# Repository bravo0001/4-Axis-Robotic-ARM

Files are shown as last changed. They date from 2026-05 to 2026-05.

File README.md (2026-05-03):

# 🦾 Wireless 4-DOF Robotic Arm




A wireless 4-Degrees-of-Freedom (4-DOF) robotic arm featuring a custom ESP32-based motherboard, **ESP-NOW peer-to-peer communication** for ultra-low-latency control, **12V DC motors** driven by relay H-Bridges, and **potentiometer-based absolute closed-loop feedback** processed through a **Kalman Filter** for smooth, noise-free motion. The system is controlled by a natural interface (wearable glove + IMUs + fingertip buttons). This project demonstrates advanced PCB design, digital signal processing, and industrial-grade mechatronics.

---

## 📐 System Architecture

```
┌─────────────────────────────────┐        ESP-NOW (P2P)        ┌─────────────────────────────────┐
│         TRANSMITTER             │ ──────────────────────────► │         RECEIVER / MOTHERBOARD  │
│                                 │       ~1ms latency          │                                 │
│  ESP32 DevKit                   │                             │  ESP32 Custom PCB               │
│  2x MPU-6050(IMU Sensor)        │                             │  4× 12V DC Motors               │
│  Kalman Filter (on-board)       │                             │  8× SPDT Relay H-Bridge         │
│  Reads 4-axis orientation       │                             │  4× 10kΩ Potentiometers (ADC1)  |
│                                 |                             |  12v Booster module             |
│                                 │                             │  Closed-Loop State Machine      │
└─────────────────────────────────┘                             └─────────────────────────────────┘
```

---

## ✨ Key Features

| Feature | Detail |
|---|---|
| **Communication** | ESP-NOW (Peer-to-Peer, no router required) |
| **Latency** | ~1 ms wireless transmission |
| **Degrees of Freedom** | 4-DOF (Base, Shoulder, Elbow, Wrist) |
| **Feedback** | Closed-loop absolute encoding via 10kΩ potentiometers |
| **ADC Pins (Feedback)** | GPIO 34, 35, 36, 39 (ADC1 — safe with Wi-Fi/ESP-NOW) |
| **Signal Processing** | Kalman Filter for IMU noise reduction |
| **Control Interface** | Natural wearable glove (IMUs + fingertip buttons) |
| **Motor Drive** | 12V DC motors via Relay H-Bridge circuits |
| **Firmware Architecture** | Non-blocking state machine on Receiver |

---

## 📁 Repository Structure

```
4-Axis-Robotic-ARM/
├── Firmware/
│   ├── Transmitter/
│   │   └── Transmitter.ino        # ESP32 transmitter: IMU read + Kalman + ESP-NOW send
│   └── Receiver/
│       └── Receiver.ino           # ESP32 receiver: ESP-NOW recv + state machine + motor control
├── Calibration/
│   ├── All_Axis_Calibration.ino   # Multi-axis potentiometer calibration (all 4 axes simultaneously)
│   ├── Axis_degree_calibration.ino # Single-axis calibration for debugging individual axes
│   └── README.md                  # Calibration documentation
├── Hardware/
│   ├── Schematics/
│   │   └── PLACEHOLDER.md         # Add KiCad / Eagle schematic files here
│   ├── Transmitter_glove-Natural_interface/
│   │   ├── Glove.jpeg             # Wearable transmitter glove overview (palm ESP32 + forearm band)
│   │   ├── Buttons.jpg            # Fingertip push-buttons for gripper control (open/close)
│   │   └── MPUS.jpg               # MPU-6050 sensor placement (forearm + palm)
│   └── PCB_Gerbers/
│       └── PLACEHOLDER.md         # Add Gerber files for PCB fabrication here
├── .gitignore                     # Arduino / PlatformIO ignores
├── LICENSE                        # MIT License
└── README.md
```

---

## ⚙️ Technical Specifications

### Communication
- **Protocol:** ESP-NOW (IEEE 802.11 based, Layer 2)
- **Topology:** Point-to-Point (Transmitter → Receiver)
- **Payload:** Custom `struct` carrying 4-axis angle data (floats)
- **Range:** Up to ~200 m line-of-sight
- **Latency:** ~1 ms

### Transmitter (ESP32 + IMU)
- Reads raw accelerometer & gyroscope data from IMU ( MPU-6050 via I²C)
- Applies **Kalman Filter** to fuse accel + gyro and eliminate sensor drift/noise
- Packs filtered 4-axis angles into a data packet and transmits via ESP-NOW

### Transmitter (Wearable Glove Interface)
The transmitter is implemented as a wearable, natural interface: a glove with an ESP32 mounted on the palm and a small forearm band. The wearable contains two MPU-6050 IMUs and two fingertip push-buttons used to control the gripper. This setup maps natural arm and hand motions into robot joint commands for intuitive control.

- **Forearm band MPU-6050**: mounted on the arm band to capture arm orientation (used for arm/base/shoulder control — X and Z axes).
- **Palm MPU-6050**: mounted on the palm to capture hand/wrist orientation (X axis).
- **ESP32 (palm-mounted)**: reads both IMUs over I²C and the fingertip push-buttons, packs orientation and button states into the ESP-NOW payload, and transmits to the Receiver.
- **Fingertip buttons**: two discrete push-buttons embedded at the fingertips — mapped to gripper actions (open / close).

Usage and mapping notes:
- Forearm MPU → arm orientation (map to base/shoulder as configured in `Transmitter.ino`).
- Palm MPU → wrist/hand orientation (map to wrist joint in the receiver state machine).
- Buttons → gripper open/close flags included in the ESP-NOW packet (sent as `uint8_t` or `bool` fields).
- This wearable arrangement is intended as a natural interface: the user performs normal arm/hand motions and fingertip presses to control the robotic arm and gripper.

Practical tips:
- Use I2C for both IMUs; if both sensors share the same address use a small I2C multiplexer or reconfigure addresses where supported.
- Debounce button inputs in firmware (software debounce or simple RC hardware) to avoid spurious commands.
- Calibrate each IMU and verify axis alignment between sensor frames and the robot joint frames before relying on production mappings.
- Keep the ESP32's ground common with the sensor grounds; use short wiring for the palm MPU for best results.

Suggested addition to the ESP-NOW payload (example):
```cpp
typedef struct {
  float axis1_angle;
  float axis2_angle;
  float axis3_angle;
  float axis4_angle;
  uint8_t gripper_open;   // 0/1
  uint8_t gripper_close;  // 0/1
} RoboArmPacket;
```

These fields allow the receiver to process continuous orientation values and discrete gripper commands together.

**Wearable photos**

Below are photos of the actual wearable transmitter (glove + forearm band) used as the natural interface. The palm-mounted ESP32, the two MPU-6050 modules (palm + forearm), and the fingertip push-buttons are shown.

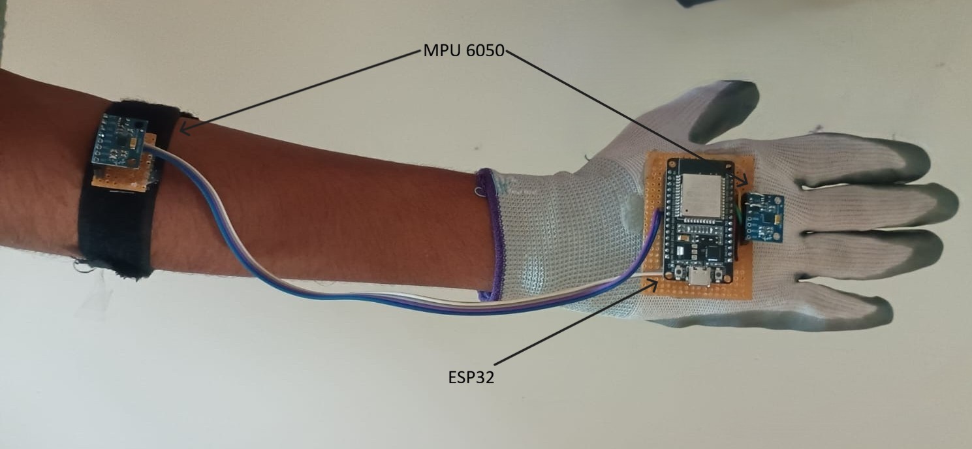
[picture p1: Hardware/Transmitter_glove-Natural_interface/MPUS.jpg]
Palm view — ESP32 and palm MPU mounted on glove


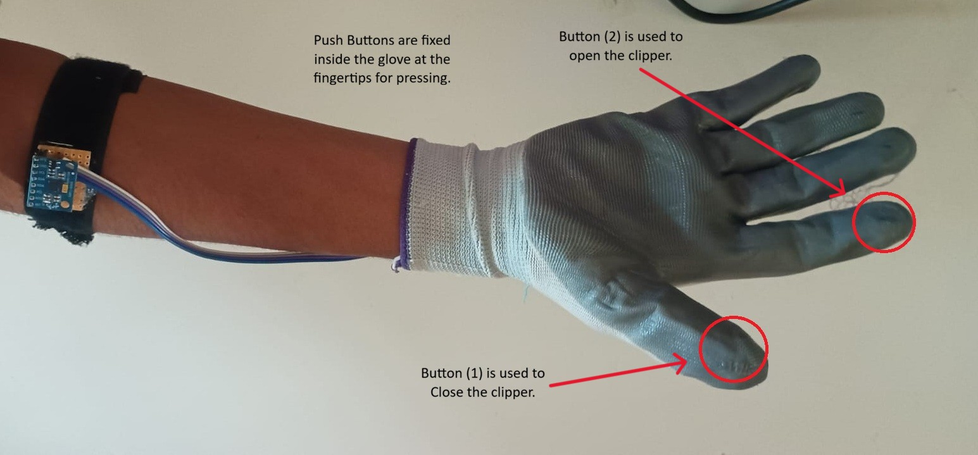
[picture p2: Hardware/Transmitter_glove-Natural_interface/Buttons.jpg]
Fingertip buttons — two push-buttons embedded at fingertips (open/close gripper)


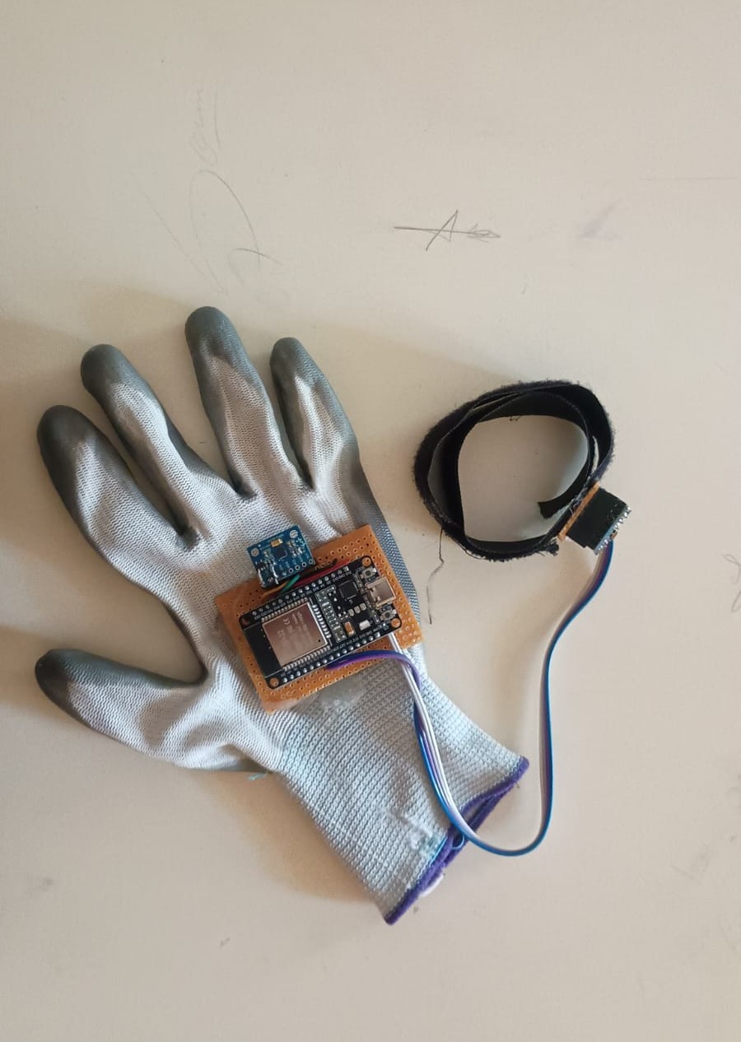
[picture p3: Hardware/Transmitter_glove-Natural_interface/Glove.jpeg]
Overview — forearm band MPU, wiring to palm MPU and ESP32


Firmware/VID_20260423_234357317.mp4~2.mp4
### Receiver / Motherboard (Custom ESP32 PCB)
- Receives angle packets via `OnDataRecv` ESP-NOW callback (interrupt-driven)
- Runs a **non-blocking state machine** for each axis to drive motors to target positions
- Reads current joint positions from 10kΩ potentiometers on **ADC1 pins** (GPIO 34, 35, 36, 39)
  - ADC1 is used because ADC2 is unavailable when Wi-Fi / ESP-NOW is active
- Drives **12V DC motors** via Relay H-Bridge circuits (direction + enable control)

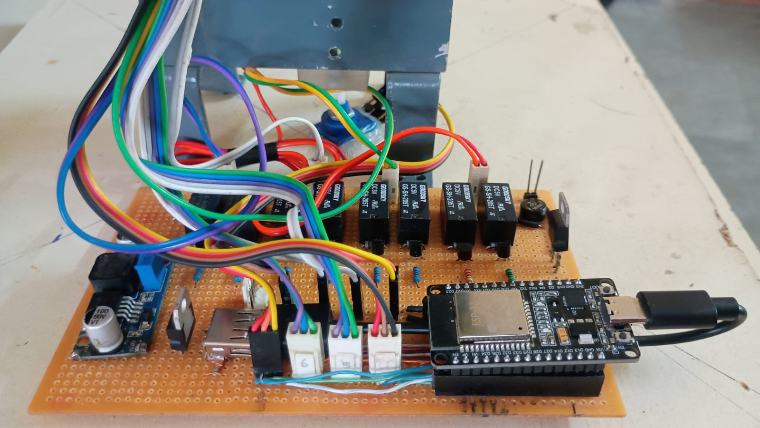
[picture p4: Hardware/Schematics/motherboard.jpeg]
Receiver / Motherboard — assembled ESP32 motherboard and relay board


**Demonstration video**

See the demo to understand the system in action. Add a `demo.mp4` file to `Firmware/Demo/` or provide a YouTube link and paste it below. Example embed (YouTube):

<table>
  <tr>
    <td width="400">
      <video src="https://github.com/user-attachments/assets/9cfaaa7f-c85e-4afe-878e-ee82e51a2cbb" controls>
      </video>
    </td>
  </tr>
</table>

If you have a local mp4 file named `demo.mp4`, place it in `Hardware/Demo/` and GitHub will render a downloadable file; to stream in README, upload the video to YouTube and embed as above for best compatibility.

### Feedback / Encoding
- **Type:** Absolute analog encoding (no homing required on power-up)
- **Sensor:** 10kΩ potentiometer per axis
- **ADC Resolution:** 12-bit (0–4095 mapped to 0°–270°)
- **Pins:** GPIO 34 (Axis 1), GPIO 35 (Axis 2), GPIO 36 (Axis 3), GPIO 39 (Axis 4)

### Kalman Filter (Digital Signal Processing)
- Single-variable discrete Kalman Filter implemented in C++
- **State:** Joint angle (degrees)
- **Process noise (Q):** Tunable — accounts for motor vibration & mechanical play
- **Measurement noise (R):** Tunable — accounts for ADC quantisation & potentiometer noise
- Runs on both Transmitter (IMU fusion) and Receiver (feedback smoothing)

---

## � Calibration

The `/Calibration/` folder contains two Arduino sketches for calibrating and testing the potentiometer feedback system:

### `All_Axis_Calibration.ino`
- Reads all four potentiometer axes simultaneously (GPIO 34, 35, 36, 39)
- Displays raw ADC values, voltage readings, and calculated angles in real-time
- Useful for verifying all axes are functioning correctly
- **Update interval:** 250 ms

### `Axis_degree_calibration.ino`
- Single-axis debugging sketch targeting GPIO 34
- Ideal for troubleshooting individual potentiometer connections
- Displays detailed readings: raw value, voltage, and angle
- **Update interval:** 100 ms

**Usage:**
1. Upload the desired calibration sketch to the Receiver ESP32
2. Open Serial Monitor at **115200 baud**
3. Rotate each potentiometer and verify the readings are linear and within expected ranges (0°–270°)
4. Adjust potentiometer range constants (270.0) in the code if your sensors have different specifications

### Running All_Axis_Calibration.ino
Upload and run this sketch on the Receiver ESP32 to simultaneously test all four potentiometers:
```cpp
// Array of pins you want to read
const int potPins[] = {34, 35, 36, 39};
const int numPins = 4;

void setup() {
  Serial.begin(115200);
  
  // ESP32 ADC setup
  analogReadResolution(12); // 0-4095 range
  analogSetAttenuation(ADC_11db); // Standard for 0-3.3V range

  Serial.println("Multi-Pin Potentiometer Initialization...");
}

void loop() {
  for (int i = 0; i < numPins; i++) {
    int rawValue = analogRead(potPins[i]);
    
    // Calculate voltage and degrees
    float voltage = rawValue * (3.3 / 4095.0);
    float degrees = (rawValue / 4095.0) * 270.0;

    // Print label for each pin
    Serial.print("PIN "); 
    Serial.print(potPins[i]);
    Serial.print(": [Raw: ");
    Serial.print(rawValue);
    Serial.print(" | Volts: ");
    Serial.print(voltage, 2);
    Serial.print("V | Ang: ");
    Serial.print(degrees, 1);
    Serial.print("°]   ");
  }
  
  Serial.println();
  delay(250); // Delay for readability
}
```

**Expected Serial Output:**
```
Multi-Pin Potentiometer Initialization...
PIN 34: [Raw: 2048 | Volts: 1.65V | Ang: 135.0°]   PIN 35: [Raw: 1024 | Volts: 0.83V | Ang: 67.5°]   PIN 36: [Raw: 3072 | Volts: 2.48V | Ang: 202.5°]   PIN 39: [Raw: 512 | Volts: 0.41V | Ang: 33.8°]
```

### Running Axis_degree_calibration.ino
Upload and run this sketch for debugging a single potentiometer:
```cpp
const int potPin = 34; // Analog pin for potentiometer

void setup() {
  Serial.begin(115200);
  analogReadResolution(12); // 0-4095 range
}

void loop() {
  int rawValue = analogRead(potPin);
  
  float voltage = rawValue * (3.3 / 4095.0);
  float degrees = (rawValue / 4095.0) * 270.0;

  Serial.print("Raw: ");
  Serial.print(rawValue);
  Serial.print(" | Voltage: ");
  Serial.print(voltage);
  Serial.print("V | Angle: ");
  Serial.print(degrees);
  Serial.println("°");

  delay(100);
}
```

**Troubleshooting Calibration:**
- **Erratic readings:** Check potentiometer wires for loose connections; verify ADC pin is correct
- **Non-linear values:** Potentiometer may be damaged; try a different unit
- **Out of range (>270°):** Adjust the 270.0 multiplier based on your potentiometer's actual rotation range
- **Stuck at min/max:** Check for mechanical binding or wiring issues

---

## �🚀 Getting Started

### Prerequisites
- [Arduino IDE](https://www.arduino.cc/en/software) ≥ 2.x **or** [PlatformIO](https://platformio.org/)
- ESP32 Arduino core (`espressif/arduino-esp32`)
- Library: `MPU6050` by Electronic Cats (or equivalent IMU library)

### Hardware Required
| Component | Qty |
|---|---|
| ESP32 DevKit v1 | 2 |
| MPU-6050 IMU Module | 2 |
| 12V DC Gear Motor | 4 |
| SPDT Relay H-Bridge (e.g., BTS7960) | 8 |
| 10kΩ Rotary Potentiometer | 4 |
| 12V DC Power Supply | 1 |
| 3.3V / 5V Logic Power | 1 |

### Flashing the Firmware

1. **Clone the repository:**
   ```bash
   git clone https://github.com/bravo0001/4-Axis-Robotic-ARM.git
   ```

2. **Flash the Transmitter:**
   - Open `Firmware/Transmitter/Transmitter.ino` in Arduino IDE
   - Select **Board:** `ESP32 Dev Module`
   - Update `receiverMacAddress[]` with your Receiver ESP32's MAC address
   - Upload

3. **Flash the Receiver:**
   - Open `Firmware/Receiver/Receiver.ino` in Arduino IDE
   - Select **Board:** `ESP32 Dev Module`
   - Upload

### Finding the Receiver MAC Address
Upload and run the following sketch on the Receiver ESP32 to print its MAC:
```cpp
#include <WiFi.h>
void setup() {
  Serial.begin(115200);
  Serial.println(WiFi.macAddress());
}
void loop() {}
```

---

## 📡 ESP-NOW Data Packet

```cpp
typedef struct {
  float axis1_angle;   // Base        (degrees)
  float axis2_angle;   // Shoulder    (degrees)
  float axis3_angle;   // Elbow       (degrees)
  float axis4_angle;   // Wrist       (degrees)
} RoboArmPacket;
```

---

## 🗂 Hardware Files

Schematic and PCB Gerber file placeholders are located in `/Hardware/`. Add your design files there:

- `/Hardware/Schematics/` — KiCad `.kicad_sch`, Eagle `.sch`, or exported PDF schematics
- `/Hardware/PCB_Gerbers/` — Gerber files (`.gbr`), drill files (`.drl`) for PCB fabrication

---

## 📜 License

This project is licensed under the **MIT License** — see the [LICENSE](LICENSE) file for details.

---

## 🙌 Contributing

Pull requests are welcome. For major changes, please open an issue first to discuss what you would like to change.

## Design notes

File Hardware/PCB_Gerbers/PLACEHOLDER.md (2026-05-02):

# Hardware — PCB Gerber Files

Place your PCB fabrication files in this directory.

## Required Gerber Layers

| Layer | Description | Typical Extension |
|---|---|---|
| Top Copper | F.Cu | `.gtl` / `F_Cu.gbr` |
| Bottom Copper | B.Cu | `.gbl` / `B_Cu.gbr` |
| Top Silkscreen | F.Silks | `.gto` / `F_Silkscreen.gbr` |
| Bottom Silkscreen | B.Silks | `.gbo` / `B_Silkscreen.gbr` |
| Top Solder Mask | F.Mask | `.gts` / `F_Mask.gbr` |
| Bottom Solder Mask | B.Mask | `.gbs` / `B_Mask.gbr` |
| Board Outline | Edge.Cuts | `.gko` / `Edge_Cuts.gbr` |
| Drill File | PTH / NPTH | `.drl` / `.xln` |

## Recommended Fabrication Services

- [JLCPCB](https://jlcpcb.com)
- [PCBWay](https://www.pcbway.com)
- [OSH Park](https://oshpark.com)

## Contents (add your files below)

- `Receiver_Motherboard/` — Gerber set for the custom ESP32 Receiver PCB
- `Transmitter_Controller/` — Gerber set for the Transmitter PCB (if custom)

## PCB Specifications (target)

| Parameter | Value |
|---|---|
| Layers | 2 |
| Board thickness | 1.6 mm |
| Copper weight | 1 oz |
| Min trace / space | 0.15 mm / 0.15 mm |
| Surface finish | HASL or ENIG |

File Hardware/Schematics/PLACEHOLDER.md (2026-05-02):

# Hardware — Schematics

Place your schematic files in this directory.

## Supported Formats

| Tool | File Extensions |
|---|---|
| KiCad | `.kicad_sch`, `.kicad_pro` |
| Eagle / Fusion 360 | `.sch`, `.brd` |
| EasyEDA | `.json` |
| PDF Export | `.pdf` |

## Contents (add your files below)

- `Receiver_Motherboard.kicad_sch` — Custom ESP32 PCB schematic
- `Transmitter_Controller.kicad_sch` — Transmitter ESP32 + IMU schematic

## Key Net / Signal Reference

| Signal | Description |
|---|---|
| `POT_AXIS1` | Potentiometer wiper → GPIO 34 |
| `POT_AXIS2` | Potentiometer wiper → GPIO 35 |
| `POT_AXIS3` | Potentiometer wiper → GPIO 36 |
| `POT_AXIS4` | Potentiometer wiper → GPIO 39 |
| `M1_FWD` / `M1_REV` | Relay H-Bridge control for Motor 1 |
| `M2_FWD` / `M2_REV` | Relay H-Bridge control for Motor 2 |
| `M3_FWD` / `M3_REV` | Relay H-Bridge control for Motor 3 |
| `M4_FWD` / `M4_REV` | Relay H-Bridge control for Motor 4 |
| `12V_MOTOR` | 12V supply rail for DC motors |
| `3V3` | 3.3V rail for ESP32 & logic |
| `GND` | Common ground |

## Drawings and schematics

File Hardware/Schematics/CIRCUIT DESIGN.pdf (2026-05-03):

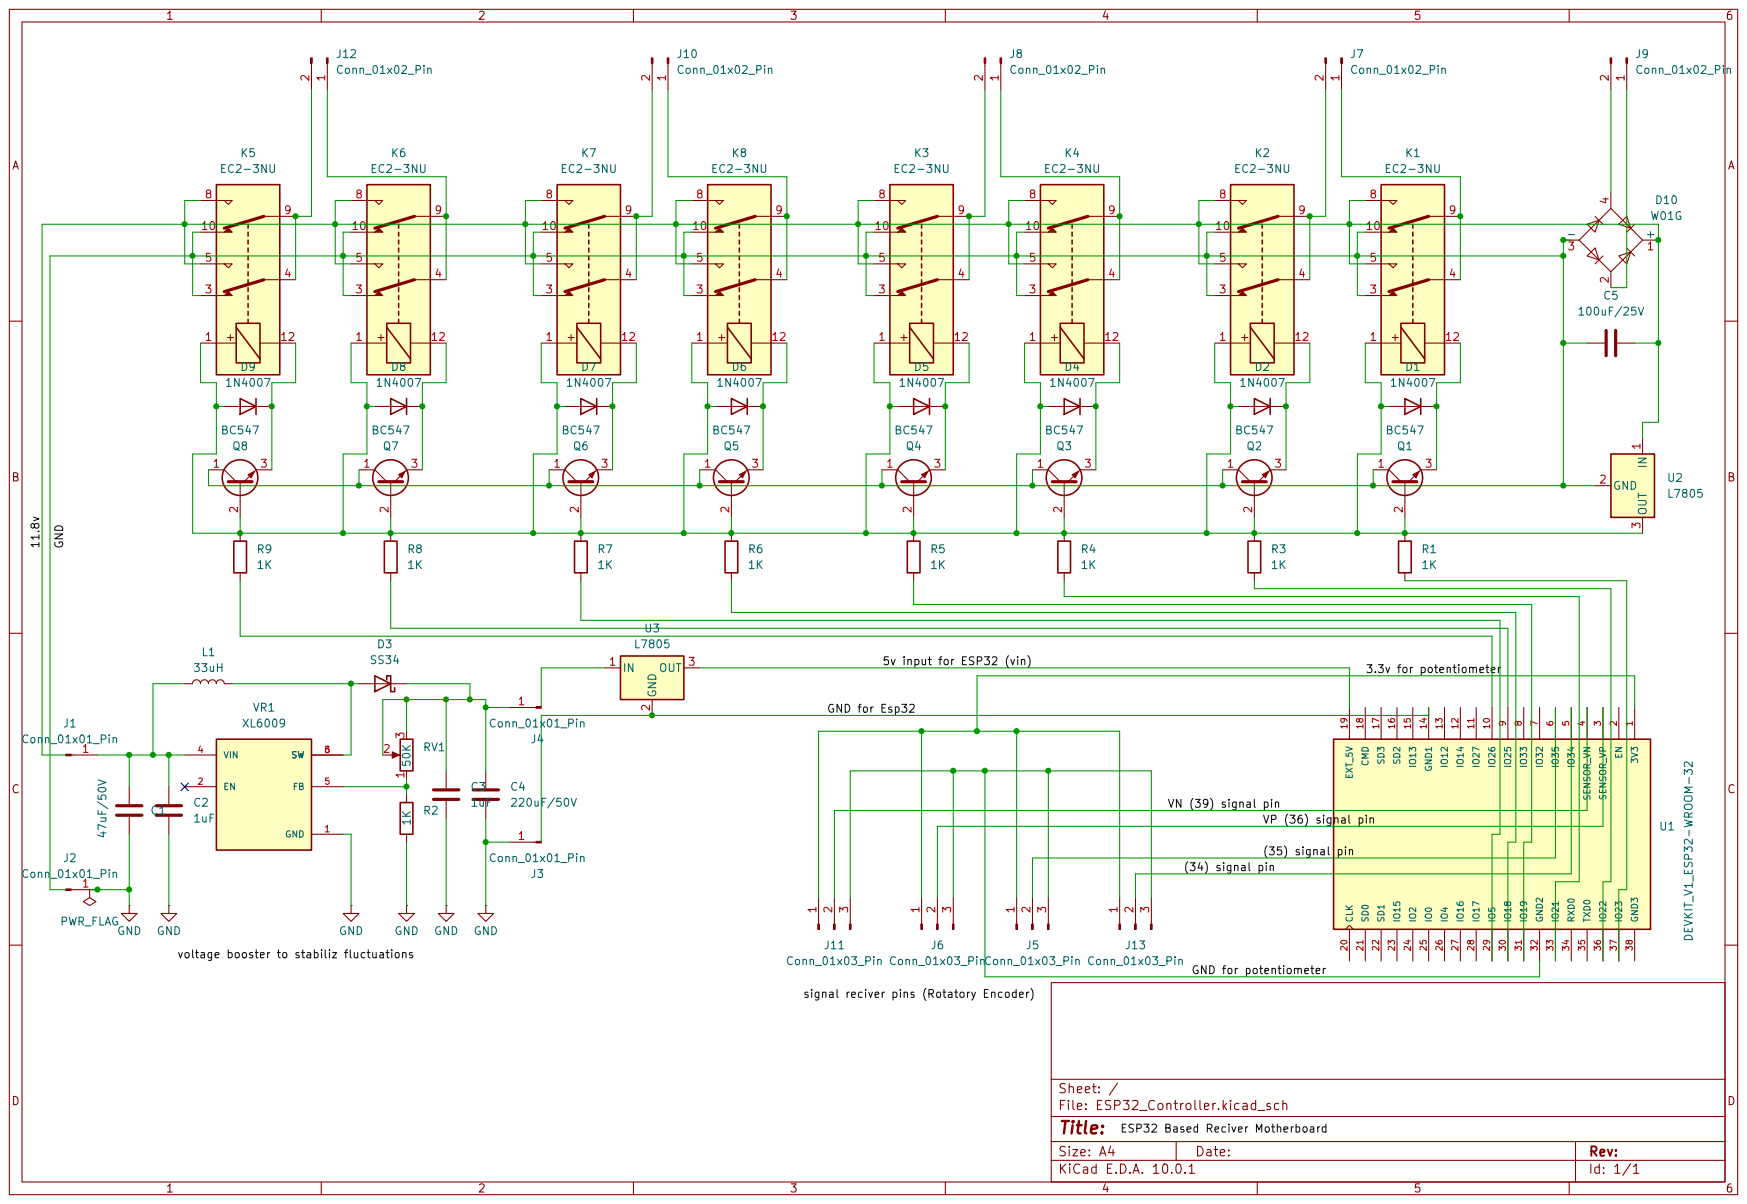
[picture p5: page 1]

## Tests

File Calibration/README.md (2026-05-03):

# Calibration Scripts

This folder contains Arduino sketches for calibrating the robotic arm's potentiometer axes.

## Files

### `All_Axis_Calibration.ino`
Simultaneously reads and displays data from all four potentiometer pins (ESP32 pins 34, 35, 36, 39).

**Features:**
- Reads all 4 axis potentiometers at once
- Displays raw ADC values, voltage readings, and calculated angles
- Uses 12-bit ADC resolution (0-4095 range)
- 3.3V input range with attenuation set to ADC_11db
- Updates every 250ms

**Output Format:**
```
PIN [pin#]: [Raw: [value] | Volts: [voltage]V | Ang: [degrees]°]
```

### `Axis_degree_calibration.ino`
Single axis calibration sketch for debugging individual potentiometer axis (pin 34).

**Features:**
- Tests one potentiometer at a time
- Displays raw ADC value, voltage, and calculated angle
- Assumes 270-degree potentiometer range
- Updates every 100ms

**Usage:**
1. Upload the appropriate sketch to your ESP32
2. Open the Serial Monitor (115200 baud)
3. Rotate potentiometer and observe readings
4. Adjust calibration values as needed in the code

**Note:** Both sketches assume a 270° potentiometer range. Modify the range value (270.0) if your potentiometers have different specifications.

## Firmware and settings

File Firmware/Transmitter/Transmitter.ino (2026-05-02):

/**
 * @file    Transmitter.ino
 * @brief   Wireless 4-DOF Robotic Arm — Transmitter Firmware
 *
 * Hardware : ESP32 DevKit + MPU-6050 IMU (I²C)
 * Protocol : ESP-NOW (Peer-to-Peer, no router required)
 * DSP      : Kalman Filter for accelerometer / gyroscope fusion
 *
 * Reads 4-axis orientation from the IMU, filters with a Kalman filter,
 * and broadcasts the result to the Receiver via ESP-NOW ~every 20 ms.
 *
 * Steps to use:
 *  1. Upload this sketch to the Transmitter ESP32.
 *  2. Set `receiverMacAddress` to the MAC address of your Receiver ESP32.
 *     (Run `WiFi.macAddress()` on the Receiver to find it.)
 *
 * MIT License — Copyright (c) 2026 Priyanshu Arya
 */

#include <esp_now.h>
#include <WiFi.h>
#include <Wire.h>

// --- BUTTON PINS FOR 4th MOTOR ---
#define BTN_F 14  // Move 4th Motor Forward
#define BTN_B 12  // Move 4th Motor Back

// --- RECEIVER MAC ADDRESS ---
uint8_t broadcastAddress[] = {0xD, 0xE9, 0xF4, 0x69, 0x37, 0x34}; 

const int MPU_addr = 0x68; 

class HeavyKalman {
  public:
    float Q_angle = 0.001f, Q_bias = 0.003f, R_measure = 0.03f;
    float angle = 0, bias = 0;  
    float P[2][2] = {{0, 0}, {0, 0}};

    float getAngle(float newAngle, float newRate, float dt) {
      float rate = newRate - bias;
      angle += dt * rate;
      P[0][0] += dt * (dt * P[1][1] - P[0][1] - P[1][0] + Q_angle);
      P[0][1] -= dt * P[1][1];
      P[1][0] -= dt * P[1][1];
      P[1][1] += Q_bias * dt;
      float S = P[0][0] + R_measure;
      float K[2] = {P[0][0] / S, P[1][0] / S};
      float y = newAngle - angle;
      angle += K[0] * y;
      bias += K[1] * y;
      float P00_temp = P[0][0], P01_temp = P[0][1];
      P[0][0] -= K[0] * P00_temp; P[0][1] -= K[0] * P01_temp;
      P[1][0] -= K[1] * P00_temp; P[1][1] -= K[1] * P01_temp;
      return angle;
    };
};

struct SensorData {
  float home_pitch = 0;
  float gyroX_offset = 0;
  float gyroZ_offset = 0;
  float z_angle = 0;      
  HeavyKalman kalmanX;
};

// --- UPDATED DATA STRUCTURE ---
typedef struct struct_message {
    float x; // Arm Pitch
    float y; // Wrist Roll
    float z; // Arm Yaw
    int btnF; // 4th Motor Forward (1 or 0)
    int btnB; // 4th Motor Back (1 or 0)
} struct_message;

struct_message myData;
esp_now_peer_info_t peerInfo;
SensorData mpu1, mpu2;
unsigned long timer;

void OnDataSent(const wifi_tx_info_t *tx_info, esp_now_send_status_t status) {}

int16_t readRaw(TwoWire &bus, int reg) {
    bus.beginTransmission(0x68);
    bus.write(reg);
    if (bus.endTransmission(false) != 0) return -999; 
    bus.requestFrom(0x68, 2);
    if (bus.available() < 2) return -999;
    return (bus.read() << 8 | bus.read());
}

void setupSensor(TwoWire &bus) {
  bus.beginTransmission(MPU_addr);
  bus.write(0x6B); bus.write(0);    
  bus.endTransmission();
}

void processMPU(TwoWire &bus, SensorData &data, float dt, bool onlyX) {
  int16_t ax = readRaw(bus, 0x3B);
  int16_t ay = readRaw(bus, 0x3D);
  int16_t az = readRaw(bus, 0x3F);
  int16_t gx = readRaw(bus, 0x43);
  int16_t gz = readRaw(bus, 0x47);

  if(ax == -999) return; 

  float accX = (atan2(-ax, sqrt((long)ay * ay + (long)az * az)) * 180 / M_PI) - data.home_pitch;
  float gyroXrate = (gx - data.gyroX_offset) / 131.0;
  data.kalmanX.getAngle(accX, gyroXrate, dt);

  if (!onlyX) {
    float gyroZrate = (gz - data.gyroZ_offset) / 131.0;
    if (abs(gyroZrate) > 0.8) data.z_angle += gyroZrate * dt;
  }
}

void calibrateAll(TwoWire &bus, SensorData &data) {
  float sumP = 0, sumGX = 0, sumGZ = 0;
  for (int i = 0; i < 200; i++) {
    int16_t ax = readRaw(bus, 0x3B);
    int16_t ay = readRaw(bus, 0x3D);
    int16_t az = readRaw(bus, 0x3F);
    sumP += atan2(-ax, sqrt((long)ay * ay + (long)az * az)) * 180 / M_PI;
    sumGX += readRaw(bus, 0x43);
    sumGZ += readRaw(bus, 0x47);
    delay(2);
  }
  data.home_pitch = sumP / 200.0;
  data.gyroX_offset = sumGX / 200.0;
  data.gyroZ_offset = sumGZ / 200.0;
}

void setup() {
  Serial.begin(115200);
  
  // Initialize Buttons with Pullups
  pinMode(BTN_F, INPUT_PULLUP);
  pinMode(BTN_B, INPUT_PULLUP);

  WiFi.mode(WIFI_STA);
  esp_now_init();
  esp_now_register_send_cb(OnDataSent);
  
  memcpy(peerInfo.peer_addr, broadcastAddress, 6);
  peerInfo.channel = 0;  
  peerInfo.encrypt = false;
  esp_now_add_peer(&peerInfo);

  Wire.begin(21, 22);   
  Wire1.begin(33, 32);  

  setupSensor(Wire);
  setupSensor(Wire1);

  Serial.println("HEAVY CALIBRATION...");
  calibrateAll(Wire, mpu1);
  calibrateAll(Wire1, mpu2);
  
  timer = micros();
}

void loop() {
    float dt = (float)(micros() - timer) / 1000000.0;
    timer = micros();

    processMPU(Wire, mpu1, dt, true); 
    
    int16_t testRead = readRaw(Wire1, 0x3B);
    if (testRead == -999) {
        Serial.println("!!! MPU 2 (ARM) DISCONNECTED !!!");
        Wire1.begin(33, 32); 
    } else {
        processMPU(Wire1, mpu2, dt, false);
    }

    // --- ANALOG MAPPING ---
    myData.x = constrain(map(mpu2.kalmanX.angle, -45, 45, 21, 105), 21, 105);
    myData.y = constrain(map(mpu1.kalmanX.angle, -35, 35, 110, 250), 110, 250);
    myData.z = constrain(map(mpu2.z_angle, -45, 45, 236, 47), 47, 236);

    // --- NEW BUTTON LOGIC ---
    // Read pins. Low = Pressed (because of INPUT_PULLUP)
    myData.btnF = (digitalRead(BTN_F) == LOW) ? 1 : 0;
    myData.btnB = (digitalRead(BTN_B) == LOW) ? 1 : 0;

    esp_now_send(broadcastAddress, (uint8_t *) &myData, sizeof(myData));
     
    Serial.printf("TX -> P:%.1f R:%.1f Y:%.1f | B4:%d,%d\n", 
                  myData.x, myData.y, myData.z, myData.btnF, myData.btnB);
    delay(20); 
}

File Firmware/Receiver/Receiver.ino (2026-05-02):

/**
 * @file    Receiver.ino
 * @brief   Wireless 4-DOF Robotic Arm — Receiver / Motherboard Firmware
 *
 * Hardware : Custom ESP32 PCB
 *            4× 12V DC motors via Relay H-Bridge drivers
 *            4× 10kΩ potentiometers on ADC1 pins for absolute position feedback
 *
 * Protocol : ESP-NOW (Peer-to-Peer)
 * DSP      : Kalman Filter for potentiometer ADC noise reduction
 * Control  : Non-blocking state machine per axis
 *
 * ADC1 pins used for feedback (ADC2 unavailable while ESP-NOW/Wi-Fi is active):
 *   GPIO 34 — Axis 1 (Base)
 *   GPIO 35 — Axis 2 (Shoulder)
 *   GPIO 36 — Axis 3 (Elbow)
 *   GPIO 39 — Axis 4 (Wrist)
 *
 * MIT License — Copyright (c) 2026 Priyanshu Arya
 */



#include <esp_now.h>
#include <WiFi.h>

// --- PIN DEFINITIONS ---
const int pot1 = 36; const int m1A = 26;   const int m1B = 25; 
const int pot2 = 35; const int m2A = 21;   const int m2B = 19;
const int pot3 = 39; const int m3A = 23;   const int m3B = 22;

// --- MOTOR 4 PINS (Back and Forth) ---
const int m4_Forward = 18; 
const int m4_Back = 5;

#define MY_RX2 16
#define MY_TX2 17

// --- LIMITS & SPEED ---
const float M1_MIN = 100.0, M1_MAX = 250.0;
const float M2_MIN = 21.0,  M2_MAX = 105.0;
const float M3_MIN = 47.0,  M3_MAX = 236.0;
const float tolerance = 2.0; 

// --- FAST SMOOTHING ---
const int windowSize = 5; 
int r1[windowSize], r2[windowSize], r3[windowSize];
int i1 = 0, i2 = 0, i3 = 0;
long t1 = 0, t2 = 0, t3 = 0;

// --- UPDATED DATA STRUCTURE (Matches Transmitter) ---
typedef struct struct_message {
    float x;  // Arm Pitch
    float y;  // Wrist Roll
    float z;  // Arm Yaw
    int btnF; // 4th Motor Forward Command
    int btnB; // 4th Motor Back Command
} struct_message;

struct_message incomingData;

// Feedback Calculation
float getDeg(int pin, int* arr, long& tot, int& idx) {
  tot -= arr[idx];
  arr[idx] = analogRead(pin);
  tot += arr[idx];
  idx = (idx + 1) % windowSize;
  return ((tot / (float)windowSize) / 4095.0) * 270.0;
}

void stopM1() { digitalWrite(m1A, LOW); digitalWrite(m1B, LOW); }
void stopM2() { digitalWrite(m2A, LOW); digitalWrite(m2B, LOW); }
void stopM3() { digitalWrite(m3A, LOW); digitalWrite(m3B, LOW); }
void stopM4() { digitalWrite(m4_Forward, LOW); digitalWrite(m4_Back, LOW); }

void OnDataRecv(const esp_now_recv_info_t *info, const uint8_t *data, int len) {
  memcpy(&incomingData, data, sizeof(incomingData));
}

void setup() {
  Serial.begin(115200);
  
  // Initialize Serial2
  Serial2.begin(9600, SERIAL_8N1, MY_RX2, MY_TX2);
  
  WiFi.mode(WIFI_STA);
  if (esp_now_init() != ESP_OK) return;
  esp_now_register_recv_cb(OnDataRecv);

  // Set Motor Pins as Output
  pinMode(m1A, OUTPUT); pinMode(m1B, OUTPUT);
  pinMode(m2A, OUTPUT); pinMode(m2B, OUTPUT);
  pinMode(m3A, OUTPUT); pinMode(m3B, OUTPUT);
  
  // New 4th Motor Pins
  pinMode(m4_Forward, OUTPUT); 
  pinMode(m4_Back, OUTPUT);
  
  analogSetAttenuation(ADC_11db);
  
  for (int i = 0; i < windowSize; i++) { r1[i] = r2[i] = r3[i] = 0; }
  stopM1(); stopM2(); stopM3(); stopM4();
}

void loop() {
  // 1. Read Current Positions (Potentiometer Feedback)
  float d1 = getDeg(pot1, r1, t1, i1);
  float d2 = getDeg(pot2, r2, t2, i2);
  float d3 = getDeg(pot3, r3, t3, i3);

  // --- MOTOR 1 (Head Roll) ---
  float err1 = incomingData.y - d1;
  if (abs(err1) > tolerance) {
      bool canMoveCW = (err1 > 0 && d1 < M1_MAX);
      bool canMoveCCW = (err1 < 0 && d1 > M1_MIN);
      digitalWrite(m1A, canMoveCW); 
      digitalWrite(m1B, canMoveCCW);
  } else { stopM1(); }

  // --- MOTOR 2 (Body Up/Down) ---
  float err2 = incomingData.x - d2;
  if (abs(err2) > tolerance) {
      bool canMoveCW = (err2 > 0 && d2 < M2_MAX);
      bool canMoveCCW = (err2 < 0 && d2 > M2_MIN);
      digitalWrite(m2A, canMoveCW); 
      digitalWrite(m2B, canMoveCCW);
  } else { stopM2(); }

  // --- MOTOR 3 (Body Left/Right) ---
  float err3 = incomingData.z - d3;
  if (abs(err3) > tolerance) {
      bool canMoveCW = (err3 > 0 && d3 < M3_MAX);
      bool canMoveCCW = (err3 < 0 && d3 > M3_MIN);
      digitalWrite(m3A, canMoveCW); 
      digitalWrite(m3B, canMoveCCW);
  } else { stopM3(); }

  // --- MOTOR 4 (NEW: BUTTON CONTROL) ---
  // If btnF is 1, Pin 18 goes HIGH. If btnB is 1, Pin 5 goes HIGH.
  digitalWrite(m4_Forward, incomingData.btnF);
  digitalWrite(m4_Back, incomingData.btnB);

  // Telemetry
  static unsigned long lastP = 0;
  if (millis() - lastP > 150) { 
    Serial.printf("T:[%.1f,%.1f,%.1f] R:[%.1f,%.1f,%.1f] M4:[%d,%d]\n", 
                  incomingData.x, incomingData.y, incomingData.z, d2, d1, d3, 
                  incomingData.btnF, incomingData.btnB);
    lastP = millis();
  }
}

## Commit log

2026-05-02 Create Wireless 4-DOF Robotic Arm project scaffold
    - Professional README.md with architecture diagram, specs & BOM
    - Firmware/Transmitter/Transmitter.ino: ESP-NOW + IMU + Kalman filter
    - Firmware/Receiver/Receiver.ino: ESP-NOW OnDataRecv + state machine + motor control
    - Hardware/Schematics/PLACEHOLDER.md and Hardware/PCB_Gerbers/PLACEHOLDER.md
    - .gitignore for Arduino/PlatformIO
    Agent-Logs-Url: https://github.com/bravo0001/4-Axis-Robotic-ARM/sessions/fd88bf6e-d801-4d30-8703-28f58dff2cad
2026-05-02 Update relay module description and quantity relay
2026-05-02 Update IMU Sensor description in README
2026-05-02 Refine IMU description in README
    Removed unnecessary 'e.g.' from IMU description.
2026-05-03 Add Calibration folder with potentiometer calibration scripts
2026-05-03 Update README with Calibration folder documentation
2026-05-03 Add detailed calibration sketch documentation with code examples
2026-05-03 Add motherboard schematic image to Hardware/Schematics directory
2026-05-03 Update MPU-6050 IMU Module quantity to 2
